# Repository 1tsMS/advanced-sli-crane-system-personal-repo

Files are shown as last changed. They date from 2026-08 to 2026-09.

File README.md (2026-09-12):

# BE Capstone Project

## Project Title

**Advanced SLI**

---

## Team Details

| Sr. No. | Name of Student | Roll No. | Branch | Email ID |
|---|---|---|---|---|
| 1 | Mohammed Salah Altaf Chogle | 41 | Automation & Robotics | 2023.mohammed.chogle@ves.ac.in |
| 2 | Ali Kalsekar | 53 | Automation & Robotics | d2024.ali.kalsekar@ves.ac.in |
| 3 | Aayush Kadam | 51 | Automation & Robotics | 2023.aayush.kadam@ves.ac.in |
| 4 |  |  |  |  |

---

## Guide Details

**Project Guide:** Gopalkrishnan Narayanan 
**Department:** Automation and Robotics  
**Institute:** VESIT, Mumbai  

---

## Problem Statement

> The aim of this project is to design and develop an affordable, retrofittable Safe Load Indicator (SLI) system for low-capacity truck-mounted pick-and-carry mobile cranes by using multi-sensor feedback (load, angle, extension, inertial data) and embedded control technology, addressing the lack of accurate, low-cost load-monitoring and safety systems available for this crane category.

---

## Abstract

Low-capacity truck-mounted pick-and-carry hydraulic cranes, commonly used at local worksites, largely lack accurate and affordable Safe Load Indicator (SLI) systems, unlike larger construction-grade cranes which have factory-fitted rated capacity indicators. Operators of these smaller cranes often rely on experience alone, increasing the risk of overloading and tipping incidents. This project proposes the design and development of an Advanced Intelligent Safe Load Indicator (AI-SLI): a sensor-driven system that monitors boom angle, extension, hydraulic pressure (as a proxy for load), and inertial motion data to provide real-time load percentage, safety alarms, and operational analytics.

The project is being developed in two parallel tracks: a custom-built scale-model truck-mounted crane platform (with independently actuated swing, telescopic extension, boom-lift, and cable-reeling axes, each with encoder and sensor feedback) used for mechanism validation and algorithm development, and eventual sensor integration on a real crane for field validation. The scale model itself is a standalone multi-axis robotic-arm project, combining mechanical design, embedded systems, and sensor fusion.

Software development follows a phased approach: starting with basic rated-capacity load-chart safety limits, followed by PID-based anti-sway control, tipping prediction using load and outrigger data, and eventually AI-based analytics such as inertial-data-driven operator scoring. The expected outcome is a working scale-model demonstrator validating the sensing and control approach, laying the foundation for deployment on a real crane.

---

## Objectives

1. To study existing Safe Load Indicator systems and identify gaps in affordability and availability for low-capacity truck-mounted cranes.
2. To design and build a multi-axis scale-model crane (swing, telescopic extension, boom lift, cable reeling) as a development and validation platform.
3. To design a sensor and control architecture capable of measuring load, angle, extension, and inertial motion.
4. To implement basic rated-capacity load-chart safety limit functionality.
5. To progressively implement advanced features: anti-sway control (PID) and tipping prediction.
6. To validate the developed system and, in later stages, apply learnings toward real crane sensor integration.

---

## Scope of the Project

- Design and fabrication of a multi-axis scale-model truck-mounted crane (mechanical + electrical)
- Sensor integration: load cell, IMU, magnetic encoders, limit switches
- Embedded firmware for motor control and sensor data acquisition
- Desktop dashboard application for live monitoring, data logging, and analytics
- Phased safety software: load-chart limits → anti-sway control → tipping prediction
- Data collection and testing on the scale model
- Preliminary exploration of real crane sensor integration (later phase, scope to be expanded as work progresses)

---

## Existing System

Large construction-grade cranes typically come with factory-fitted Rated Capacity Indicator (RCI) / SLI systems. However, small, local, truck-mounted pick-and-carry hydraulic cranes commonly used at smaller worksites usually operate without such systems.

Limitations of the current situation:

- High cost of commercial SLI systems relative to the value of low-capacity cranes
- Lack of retrofittable options for older or lower-capacity crane models
- Operators rely on experience/judgement rather than real-time load feedback
- No predictive safety features (e.g., sway or tipping warnings) on this crane category
- Limited accessibility of safety technology for smaller crane operators

---

## Proposed System

**Main idea:** An affordable, sensor-driven Safe Load Indicator system, developed and validated on a custom-built scale-model crane before targeting real crane deployment.

**How it works:** Boom angle, extension length, and load/pressure are continuously measured and combined (via a load-chart lookup) to compute real-time load percentage and trigger safety alarms. Inertial (IMU) data is used to detect motion events, assist with anti-sway damping, and support operator analytics. Data is transmitted to a desktop dashboard for live monitoring and logging.

**Major components:** Multi-axis scale-model crane (swing, telescopic extension, boom lift, cable reeling), magnetic encoders, IMU, load cell, microcontroller-based control system, and a PyQt6 desktop dashboard.

**Expected benefits:** Real-time load awareness, improved operator safety, a low-cost architecture suited to smaller cranes, and a foundation for future predictive safety features.

**Video** https://www.youtube.com/watch?v=u0mv6QGTxTg

---

## System Architecture

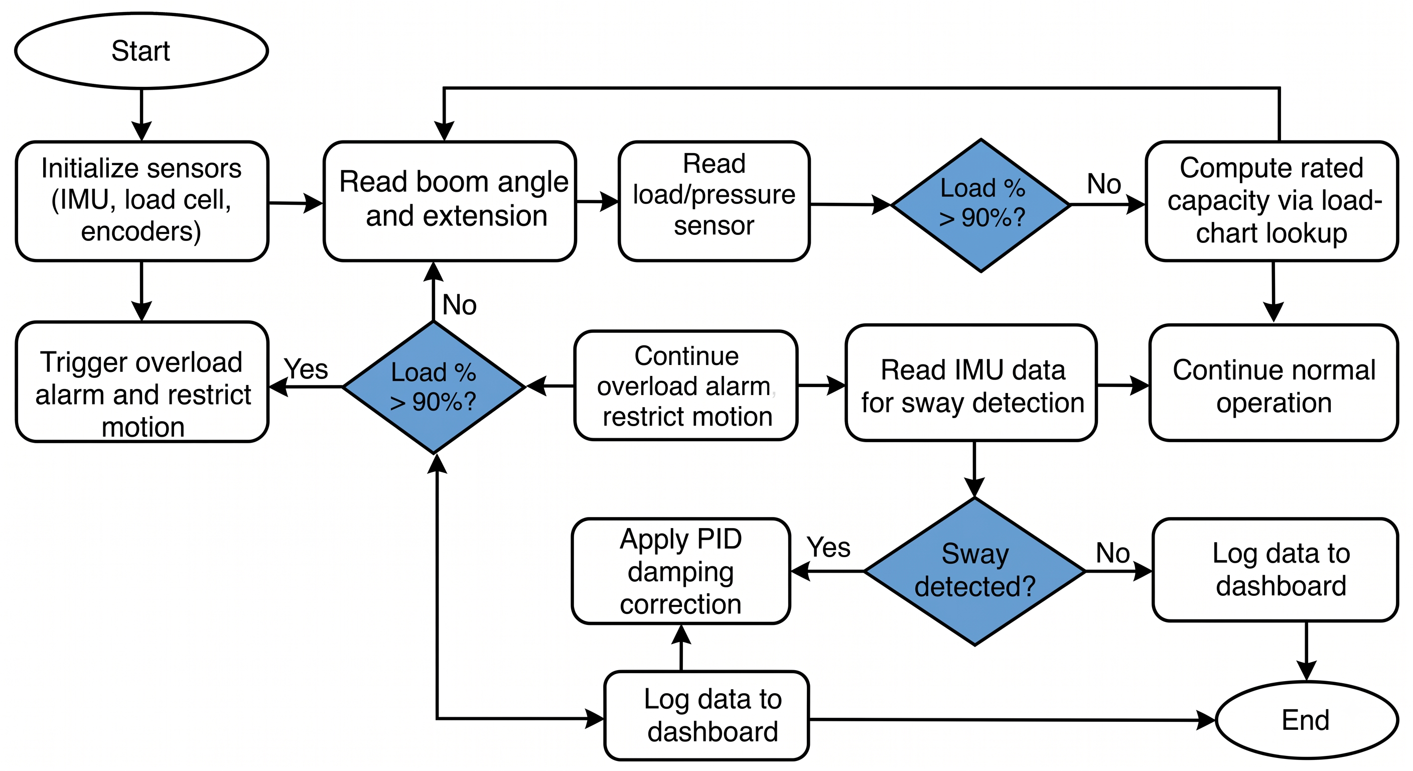
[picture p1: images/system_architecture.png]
System Architecture


---

## Hardware Requirements

| Sr. No. | Component | Specification | Quantity | Purpose |
| --- | --- | --- | --- | --- |
| 1 | NEMA17 Stepper Motor | 17HS8401 | 3 | Swing, boom lift, telescopic extension actuation |
| 2 | N20 DC Gear Motor | 150 RPM, encoder-integrated | 1 | Cable reeling / winch drive |
| 3 | Arduino Mega 2560 | — | 1 | Main controller |
| 4 | RAMPS 1.4 | — | 1 | Motor driver / sensor breakout shield |
| 5 | A4988 Stepper Driver | — | 4 | Stepper motor driving |
| 6 | AS5600 Magnetic Encoder | — | 2 | Swing and boom lift angle feedback |
| 7 | MPU6050 IMU | 6-axis | 1 | Inertial motion sensing |
| 8 | HX711 + Load Cell | 5 kg | 1 | Load sensing |
| 9 | Limit Switches | Mechanical | As required | Axis end-stop safety |
| 10 | 12V Power Supply | 12V, 10A | 1 | System power |

---

## Software Requirements

| Sr. No. | Software / Tool | Version | Purpose |
| --- | --- | --- | --- |
| 1 | Arduino IDE | — | Firmware development |
| 2 | Fusion 360 | — | Mechanical CAD design |
| 3 | Python | — | Data processing, dashboard, model training |
| 4 | PyQt6 | — | Desktop dashboard application |

---

## Technologies Used

* Embedded C++ (Arduino)
* Python (data processing, dashboard, model training)
* Arduino Mega, RAMPS 1.4, A4988 stepper drivers
* Sensor fusion (Madgwick / Kalman filtering for IMU data)
* Machine Learning (LSTM — planned for future tipping prediction phase)
* PyQt6 (desktop dashboard)
* CAD Design (Fusion 360)

---

## Methodology

Explain the step-by-step approach.

1. Literature survey
2. Problem identification
3. Requirement analysis
4. System design
5. Hardware/software development
6. Integration
7. Testing and validation
8. Documentation and publication

---

## Project Timeline

| Week / Month | Task Planned | Status |
| --- | --- | --- |
| Week 1 | Problem finalization  | Completed
| Week 2 | Literature survey | Completed |
| Week 3 | Requirement analysis  | Completed |
| Week 4 | System design | Completed |
| Week 5 | Prototype development | In Progress |
| Week 6 | Testing | Pending |
| Week 7 | Documentation | Pending |
| Week 8 | Paper writing | Pending |

---

## Weekly Progress Updates

Students must update this section every week.

| Week | Date | Work Completed | Work Planned for Next Week | Issues / Challenges | GitHub Commit Link |
| --- | ---- | --- | --- | --- | --- |
| Week 1 | Feb 2026 | Finalized problem statement | Begin literature survey	 | | |
| Week 2 | Mar 2026 | Literature survey | Incorporate review feedback, finalize scope | | |
| Week 3 | Apr 2026 | Incorporated review feedback/modifications; finalized scope for submission | Requirement analysis & component selection | | |
| Week 4 | Jul 2026 | Requirement analysis & component selection | | | |
| Week 5 | Jul 2026 | Researched mechanical systems for prototype design | | | |
| Week 6 | Jul 2026 | Mechanical design & 3D CAD modelling | | | |
| Week 7 | Aug 2026 | 3D printing of mechanical parts and assembly | | | |
| Week 8 | Aug 2026 | Prototype PCB and electronic configuration | | | |
| Week 8 | Aug 2026 | Prototype testing done | issues in model noted and updated laser cut files | | |
| Week 9 | Sep 2026 | | Sensor integration | | |
| Week 10 | Sep 2026 | | Firmware development | | |
| Week 11 | Sep 2026 | | Calibration & implement basic load-chart safety limits | | |
| Week 12 | Sep 2026 | | Build PyQt6 dashboard | | |
| Week 13 | Oct 2026 | | 	Implement PID-based anti-sway control; begin tipping-prediction groundwork | | |
| Week 14 | Oct 2026 | | 	Full system testing, bug fixes, results compilation, documentation | | |
| Week 15 | Oct 2026 | | Research paper writing | | |
---

## Design Files

Upload and link all design files here.

| File Type | File Name / Link | Description |
| --- | --- | --- |
| CAD Model | | |
| Circuit Diagram | | |
| PCB Design | | |
| Flowchart | | |
| Simulation File | | |

---

## Circuit Diagram

Add circuit diagram image here.

````markdown
![Circuit Diagram](images/circuit_diagram.png)
````

---

## Flowchart / Algorithm

Add flowchart image here.

````markdown
![Flowchart](images/flowchart.png)
````

### Algorithm

1. Start
2. Initialize the system
3. Read input from sensors/user
4. Process the data
5. Generate output/control action
6. Display/store/transmit result
7. Stop

---

## Implementation Details

Explain the actual implementation of the project.

### Hardware Implementation

Write details about connections, components, power supply, sensors, actuators, PCB, enclosure, etc.

### Software Implementation

Write details about code structure, libraries used, algorithms, communication protocols, database, app, cloud, etc.

---

## Code Structure

````text
BE-Capstone-Project/
│
├── README.md
├── docs/
│   ├── literature_survey.md
│   ├── project_report.pdf
│   └── presentation.pptx
│
├── hardware/
│   ├── circuit_diagram.png
│   ├── pcb_design/
│   └── cad_model/
│
├── software/
│   ├── src/
│   ├── include/
│   └── tests/
│
├── images/
│   ├── system_architecture.png
│   ├── prototype_photo.jpg
│   └── results.png
│
└── references/
    └── papers/
````

---

## How to Run the Project

### Step 1: Clone the Repository

````bash
git clone https://github.com/username/project-name.git
````

### Step 2: Install Dependencies

````bash
pip install -r requirements.txt
````

or mention specific software/library installation steps.

### Step 3: Upload / Run the Code

````bash
python main.py
````

or

````bash
arduino-cli upload -p COMx --fqbn board_name
````

### Step 4: Observe the Output

Mention the expected output of the project.

---

## Testing and Results

| Test No. | Test Description | Expected Result | Actual Result | Status |
| --- | --- | --- | --- | --- |
| 1 | | | | Pass / Fail |
| 2 | | | | Pass / Fail |
| 3 | | | | Pass / Fail |

---

## Result Images / Videos

Add images or videos of the working prototype.

````markdown
![Prototype](images/prototype_photo.jpg)
````

Video Link:

````markdown
[Project Demo Video](https://drive.google.com/your-video-link)
````

---

## Applications

Mention real-world applications of the project.

1.
2.
3.
4.

---

## Advantages

1.
2.
3.
4.

---

## Limitations

1.
2.
3.
4.

---

## Future Scope

Mention possible improvements.

1.
2.
3.
4.

---

## Research Paper / Publication

| Item | Details |
| --- | --- |
| Paper Title | |
| Conference / Journal Name | |
| Paper Status | Not Started / Drafting / Submitted / Accepted / Published |
| Submission Date | |
| Paper Link | |

---

## References

Add references in IEEE format.

Example:

````text
[1] Junqi Li, Qing Dong, "A Development Method for Load Adaptive Matching Digital Twin System of Bridge Cranes," Journal/Conference Name, vol. X, no. Y, pp. xx-yy, Year.
[2] Dae-Ho Jang, Gi-Tae Roh, "Simulation-Based Optimization of Crane Lifting Position and Capacity Using a Construction Digital Twin for Prefabricated Bridge Deck Assembly"
[3] Yihai Fang, Yong K. Cho, "A Framework for Real-time Pro-active Safety Assistance for Mobile Crane Lifting Operations"
[4] Datasheet / Website / Book reference.
````

---

## Repository Update Guidelines

Each student team must update the GitHub repository regularly.

Minimum expected updates:

* Update README every week.
* Push code changes regularly.
* Upload circuit diagrams, CAD files, PCB files, reports and presentations.
* Add weekly progress in the progress table.
* Maintain proper folder structure.
* Do not upload unnecessary temporary files.
* Each major update should have a meaningful commit message.

Example commit messages:

````text
Added problem statement and objectives
Updated system architecture diagram
Added sensor interfacing code
Updated weekly progress for Week 3
Added testing results and prototype images
````

---

## Declaration

We declare that this project work is carried out by our team as part of the BE Capstone Project. The work will be regularly updated on GitHub and all references used will be properly cited.

---

## License

This project is for academic use only.

Optional:

````text
MIT License / Creative Commons / Institute Use Only
````

````
````

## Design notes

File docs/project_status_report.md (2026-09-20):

# Advanced SLI — Project Status Report
**Date:** September 2026 | **Ref:** [software_design_plan.md](./software_design_plan.md)

---

## Build Phase Status

| Phase | Description | Status |
|---|---|---|
| **Phase 1** | It Talks — end-to-end data pipeline | ✅ Complete |
| **Phase 2** | It Looks Good — full UI + controls | ✅ Complete |
| **Phase 3** | It's Smart — load calculation & safety | 🔴 Pending |
| **Phase 4** | It Prevents Disaster — PID anti-sway | 🔴 Not Started |

---

## What's Done

### Layer 1 — ESP32 Firmware (FreeRTOS)
- **3-task FreeRTOS skeleton** running: `SensorTask` (100Hz, Core 1), `TelemetryTask` (50Hz, Core 0), `CommandTask` (event-driven, Core 0)
- **`$T` telemetry packet** streaming at 50Hz over USB serial — all 16 fields present and parsed
- **Custom G-code protocol** implemented — `M1–M4`, `M0 Ax`, `T0` E-stop, `CAL0–2`, `DBG`, `LC`
- **UART2 bridge** to Arduino Mega working (`GPIO23/27`)
- **All sensor drivers written and functional:**
  - `AS5600Driver` — supports all 3 buses (Wire, Wire1, SoftI2C)
  - `MPU6050Driver` — backed by `Adafruit_MPU6050`, complementary filter for roll/pitch
  - `HX711Driver` — load cell with tare and calibration factor
  - `FSRReader` — 4-channel ADC for outrigger sensors
  - `N20Encoder` — quadrature interrupt-based encoder + DRV8833 motor control
- **NVS Flash persistence** — telescope scale (`tele_scale`) and invert (`tele_inv`) survive power cycles via `Preferences`
- **Calibration commands extended** — `CAL2 S<scale> I<invert>` to tune telescope parameters at runtime without reflashing

### Layer 2 — Python Backend
- **FastAPI + pyserial** running at `localhost:8000`
- **WebSocket** telemetry broadcast at 50Hz to frontend
- **All REST endpoints** live: `/api/connect`, `/api/command`, `/api/status`, `/api/calibrate/tare|imu|tele`, `/api/estop`, `/api/debug/scan`, `/api/loadchart/*`
- **CSV session logger** — auto-logs each session with timestamp
- **Command router** with regex validation — rejects invalid commands before they hit serial
- **`TeleCalibrateRequest` model** — `CAL2 S... I...` built and sent from `/api/calibrate/tele`

### Layer 3 — Frontend Dashboard
- **Dark industrial UI** — Inter + JetBrains Mono, electric cyan accents (`#00D4FF`)
- **Sidebar navigation** — Dashboard, Debug & Calibrate, Settings, Data Logger, Load Chart (placeholder)
- **Dashboard tab** — Live telemetry panels, 3× circular arc gauges (Load%, Boom Angle, Tilt), 2D crane visualizer, outrigger FSR corner view
- **Motor Controls** — Hold-to-move buttons for all 4 axes (M1–M4), global speed slider (250–2500 steps/s, center=1000), E-stop header button
- **Xbox Gamepad API** — full axis mapping (Left Stick=Swing/Boom, Right Stick=Extend, Triggers=Winch)
- **Debug & Calibrate tab:**
  - Hardware status (I2C scan)
  - Load cell tare, IMU zero with axis mapping UI
  - **Telescope calibration panel** — live encoder readout, M3 motor jog (press-and-hold), ruler auto-calibration tool (computes scale from measured travel), manual scale/invert inputs, Save to Flash button
- **Settings tab** — COM port selection, baud, connect/disconnect
- **2D Crane Visualizer** — base boom (225mm constant) + telescoping extension stage with graduation marks + `+XX mm` badge

### Arduino Mega Executor
- Motor commands received on `Serial1` from ESP32
- 3 axes on RAMPS 1.4: **Swing → X**, **Boom Lift → Z**, **Telescope Extend → Y**
- Default speed: 1000 steps/s, range 250–2500 steps/s
- E-stop (`T0`) disables all drivers

---

## Libraries: Custom vs Standard

### Why Custom Drivers

| Component | Why not standard |
|---|---|
| `AS5600Driver` | No library supports 3 AS5600s (all fixed at `0x36`) on 3 separate buses. Custom driver takes `Wire`, `Wire1`, or `SoftI2C` as constructor arg. Essential for multi-encoder setup. |
| `SoftI2C` | ESP32 has only 2 hardware I2C peripherals. 3rd bus (telescope AS5600, GPIO32/33) needs bit-bang. AVR-targeted `SoftwareWire` won't work. Custom impl mirrors `TwoWire` API, tuned at 8µs bit delay (~60kHz) for capacitive wire lengths. |
| `HX711Driver` | Standard `HX711` library uses blocking `delay()`, which starves FreeRTOS tasks. Custom driver is non-blocking — returns cached value if data not ready, keeping `SensorTask` on its 100Hz deadline. |

### Standard Libraries Used

| Library | Layer | Role |
|---|---|---|
| `Adafruit_MPU6050` + `Adafruit_Sensor` | ESP32 | IMU hardware abstraction |
| `Preferences` (ESP-IDF built-in) | ESP32 | NVS flash key-value for calibration |
| `FreeRTOS` (bundled with ESP32 Arduino) | ESP32 | Task scheduling, mutexes, queues |
| `FastAPI` + `uvicorn` | Python | ASGI REST + WebSocket server |
| `pyserial` | Python | USB serial to ESP32 |
| `React 19` + `Vite 8` | Frontend | UI framework and build tooling |
| `Lucide React` | Frontend | SVG icon library |
| `Recharts` | Frontend | Live rolling charts |
| `Gamepad API` (W3C browser API) | Frontend | Xbox controller input |

---

## Current Issues

### 🔴 Telescope Extension — Encoder Jumpiness
- AS5600 on SoftI2C (GPIO32/33) produces spike deltas at the 0°/360° wrap boundary — 30mm physical travel was reading as 110mm.
- **Software mitigations applied:** 45° glitch gatekeeper (single-frame delta > 45° discarded), shortest-path angular accumulation, switched to `REG_ANGLE` (0x0E) for AS5600 internal hardware filter, SoftI2C bit delay increased to 8µs.
- **Current state:** Improved but still jumpy under vibration. Runtime calibration (ruler tool in Debug tab) works but is sensitive to slippage.
- **Root causes:** Long SoftI2C wires (capacitance), inconsistent magnet air-gap, AS5600 has no quadrature redundancy unlike hall-effect encoders.
- **Mechanical fix needed:** Tighten motor-to-stage coupling, reduce magnet-to-IC gap, shorten SoftI2C wiring harness.

### 🔴 N20 Winch — One Direction Not Working
- Motor only runs in reverse. Forward direction (via DRV8833 AIN1/AIN2 on GPIO13/14) produces no motion.
- **Suspected cause:** DRV8833 IC fault — one H-bridge half likely dead.
- **Action:** Replace DRV8833 module. Reverify AIN1/AIN2 polarity against `n20_test` sketch after replacement.
- **Rope length measurement:** Encoder interrupt code (GPIO18/19) is written but `N20_TICKS_PER_REV=840` and `ROPE_DRUM_DIAMETER_MM=20mm` are guesses — require physical measurement post-repair.

### 🟡 Load Cell — Not Properly Calibrated
- `HX711_DEFAULT_SCALE = 122000.0` counts/kg is a rough estimate from `loadcell_approx` test.
- No 2-point calibration with known reference weights done on final mechanical setup.
- Boom-angle compensation (`W_actual = F_measured / cos(θ)`) is planned for Phase 3 — currently `actualLoadKg` = raw reading, no compensation.

### 🟡 IMU / MPU6050 — Not Calibrated on Final Hardware
- Complementary filter active, gyro zero-offset calibration function exists (`calibrateGyro()`).
- Axis mapping UI in Debug tab implemented but proper static calibration not performed on final assembled crane.

### 🟡 Hardware — Outriggers & Hook/Rope Incomplete
- Outriggers: 3D printed and assembled. FSR sensors load. Minor adjustment needed — not all 4 corners show equal distribution under a centred load.
- Hook: Not yet designed or fabricated.
- Rope: No rope/drum assembly. N20 drum diameter unverified.

---

## Remaining Work (Priority Order)

1. Replace DRV8833 → verify N20 bidirectional operation
2. Measure actual N20 encoder ticks/rev and drum diameter → update `config.h`
3. Design and fabricate hook + rope assembly, mount on boom tip + drum
4. Proper 2-point load cell calibration → update or make `HX711_DEFAULT_SCALE` runtime-tunable
5. IMU static calibration on level assembled crane → run `CAL1`
6. Mechanical telescope fix (coupling, air-gap, wiring) → re-evaluate encoder noise
7. Outrigger FSR equalisation
8. **Phase 3 firmware:** `SafetyTask`, boom-angle load compensation, load chart lookup
9. Load Chart editor tab — upload LC entries from dashboard
10. Phase 4 — PID anti-sway (lower priority)

---

## Not Started (From Plan)

- `SafetyTask` — load chart lookup, alarm escalation
- Boom-angle compensation activated (code exists, not wired in)
- Load Chart editor UI tab
- Data Logger tab (session CSV viewer + rolling chart)
- PID anti-sway task
- 3D crane visualizer (future scope)

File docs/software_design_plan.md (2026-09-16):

# Advanced SLI — Software System Design Plan (v2)

## Overview

A three-layer software system for the Advanced Safe Load Indicator. This version incorporates RTOS fundamentals, boom-angle load compensation math, updated dashboard layout, and a phased firmware plan starting with bare telemetry.

---

## Table of Contents

1. [FreeRTOS Deep-Dive](#1--freertos-deep-dive-for-esp32)
2. [System Architecture](#2--system-architecture-3-layer)
3. [ESP32 Firmware Design](#3--layer-1--esp32-firmware-freertos)
4. [Load Calculation Physics](#4--load-calculation--boom-angle-compensation)
5. [Mega Executor Firmware](#5--mega-executor-firmware)
6. [Communication Protocol](#6--communication-protocol--custom-g-code)
7. [Python Middleware](#7--layer-2--python-middleware)
8. [Frontend Dashboard](#8--layer-3--frontend-electron--react)
9. [Folder Structure](#9--folder-structure)
10. [Build Phases](#10--build-phases)
11. [Open Decisions](#11--remaining-decisions)

---

## 1 — FreeRTOS Deep-Dive for ESP32

### What is RTOS and Why Do We Need It?

On a regular Arduino (or any bare-metal loop), your code runs like this:

```
void loop() {
    readSensors();     // takes ~5ms
    runSafetyCheck();  // takes ~2ms
    sendTelemetry();   // takes ~3ms (blocked waiting for Serial buffer)
    checkCommands();   // takes ~1ms
    controlMotors();   // takes ~1ms
}
// Total: ~12ms per cycle → ~83Hz max
// BUT: if sendTelemetry() blocks for 50ms (buffer full), EVERYTHING waits
```

**The problem**: Everything runs sequentially in one big loop. If one function takes longer than expected (sensor I2C timeout, serial buffer full, etc.), *everything* else gets delayed. Your safety check doesn't run. Your motor control stutters. Bad news for a crane.

**FreeRTOS solves this** by letting you split your code into **independent tasks** that run "at the same time". The ESP32 has **two CPU cores**, and FreeRTOS can actually run two tasks *truly in parallel* + rapidly switch between others.

### Core RTOS Concepts You Need

#### 1. Tasks (like threads)

A **task** is just a function that runs in its own infinite loop, independently from everything else. Each task has:
- A **priority** (higher priority = gets CPU time first)
- A **stack size** (memory allocated for its local variables)
- A **core assignment** (ESP32 has Core 0 and Core 1)

```cpp
// This is a FreeRTOS task — it runs forever, independently
void SensorTask(void *pvParameters) {
    while (true) {
        readAllSensors();
        vTaskDelay(pdMS_TO_TICKS(10));  // Sleep 10ms → runs at ~100Hz
    }
}

// Create it in setup()
void setup() {
    xTaskCreatePinnedToCore(
        SensorTask,     // function to run
        "SensorTask",   // name (for debug)
        4096,           // stack size in bytes
        NULL,           // parameter to pass
        5,              // priority (higher = more important)
        NULL,           // task handle (for controlling it later)
        1               // core to run on (0 or 1)
    );
}
```

#### 2. `vTaskDelay()` — Cooperative Sleeping

When a task calls `vTaskDelay(pdMS_TO_TICKS(10))`, it tells FreeRTOS: *"I'm done for now, wake me up in 10ms."* During those 10ms, **other tasks get to run**. This is how multiple tasks share a single CPU core.

> [!IMPORTANT]
> **Never use `delay()` in FreeRTOS!** Arduino's `delay()` blocks the entire core and starves other tasks. Always use `vTaskDelay()`.

#### 3. `vTaskDelayUntil()` — Precise Periodic Timing

`vTaskDelay()` sleeps for X ms *after* your work finishes. If your work takes 3ms and you delay 10ms, the actual period is 13ms — it drifts.

`vTaskDelayUntil()` sleeps *until* the next absolute time. If your period is 10ms and work takes 3ms, it sleeps exactly 7ms. Rock-solid frequency.

```cpp
void TelemetryTask(void *pvParameters) {
    TickType_t lastWakeTime = xTaskGetTickCount();
    const TickType_t period = pdMS_TO_TICKS(20);  // 50Hz exactly

    while (true) {
        sendTelemetryPacket();
        vTaskDelayUntil(&lastWakeTime, period);  // Runs at exactly 50Hz
    }
}
```

#### 4. Shared Data Problem — Queues & Mutexes

If `SensorTask` writes to `boomAngle` and `TelemetryTask` reads it at the same time, you get **data corruption** (torn reads — half-updated values). Two solutions:

**Mutex (Mutual Exclusion Lock):**
```cpp
SemaphoreHandle_t dataMutex = xSemaphoreCreateMutex();

// In SensorTask:
xSemaphoreTake(dataMutex, portMAX_DELAY);  // Lock
sensorData.boomAngle = readBoomAngle();     // Write safely
xSemaphoreGive(dataMutex);                  // Unlock

// In TelemetryTask:
xSemaphoreTake(dataMutex, portMAX_DELAY);   // Lock
float angle = sensorData.boomAngle;          // Read safely
xSemaphoreGive(dataMutex);                   // Unlock
```

**Queue (Thread-Safe Pipe):**
```cpp
QueueHandle_t commandQueue = xQueueCreate(10, sizeof(Command));

// Frontend sends command → CommandTask receives it
// Producer:
Command cmd = parseGCode("M1 S200 D1");
xQueueSend(commandQueue, &cmd, 0);

// Consumer (MotorTask):
Command received;
if (xQueueReceive(commandQueue, &received, portMAX_DELAY)) {
    executeMotorCommand(received);
}
```

#### 5. ESP32 Dual-Core Strategy

The ESP32 has **two cores**. WiFi/BLE run on Core 0 by default. We split our tasks strategically:

```
┌─────────────────────────────────────────────────┐
│                   CORE 1                         │
│  (Dedicated to time-critical real-time work)     │
│                                                  │
│  SensorTask     [100Hz, Priority 5]              │
│  SafetyTask     [50Hz,  Priority 6 — HIGHEST]    │
│  PIDTask        [50Hz,  Priority 5]              │
│                                                  │
│  → These MUST run on time, no exceptions         │
├─────────────────────────────────────────────────┤
│                   CORE 0                         │
│  (Handles communication, non-critical work)      │
│                                                  │
│  TelemetryTask  [50Hz,  Priority 3]              │
│  CommandTask    [Event, Priority 4]              │
│  MegaBridgeTask [On-demand, Priority 3]          │
│                                                  │
│  → Important but can tolerate slight delays      │
└─────────────────────────────────────────────────┘
```

**Why this split?**
- If serial communication hiccups on Core 0, your sensor reading and safety checks on Core 1 **keep running perfectly** — they're on a completely separate CPU.
- `SafetyTask` has the highest priority on Core 1, so even if `SensorTask` is mid-read, a safety alarm will preempt it immediately.

#### 6. Task Communication Flow (Our System)

```
                        ┌──────────────┐
                        │  SensorTask  │ ← reads all hardware
                        │   (Core 1)   │
                        └──────┬───────┘
                               │ writes to shared struct (mutex-protected)
                               ▼
                     ┌────────────────────┐
                     │  SensorData struct │ ← single source of truth
                     │  (mutex-guarded)   │
                     └──┬──────┬─────┬───┘
                        │      │     │
              ┌─────────▼──┐   │   ┌─▼────────────┐
              │ SafetyTask │   │   │  PIDTask      │
              │  (Core 1)  │   │   │  (Core 1)     │
              │ checks     │   │   │ anti-sway     │
              │ load limits│   │   │ compensation  │
              └─────────┬──┘   │   └──┬────────────┘
                        │      │      │
                        ▼      ▼      ▼
              ┌─────────────────────────────┐
              │     TelemetryTask (Core 0)  │
              │  reads struct → formats $T  │
              │  → Serial.println()         │
              └─────────────────────────────┘

  PC Command ──→ Serial RX ──→ CommandTask (Core 0)
                                    │
                                    ▼ (via Queue)
                              MegaBridgeTask (Core 0)
                                    │
                                    ▼ UART2
                              Arduino Mega (stepper motors)
```

#### Summary: What You Get From RTOS

| Without RTOS (bare loop) | With FreeRTOS |
|---|---|
| One thing at a time, sequentially | Multiple things truly in parallel |
| One slow function delays everything | Tasks are independent, can't block each other |
| No priority — safety check waits for serial | Safety has highest priority, always runs first |
| Timing drifts as code grows | `vTaskDelayUntil` = rock-solid frequencies |
| Hard to add features without breaking timing | Add a new task = zero impact on existing ones |

---

## 2 — System Architecture (3-Layer)

```
┌────────────────────────────────────────────────────────────────────────┐
│                     LAYER 3 — FRONTEND (Desktop App)                   │
│               Electron + React + TypeScript + Vite                      │
│  Dark Glassmorphism Industrial UI │ WebSocket Client │ Xbox Gamepad     │
└────────────────────────────────┬───────────────────────────────────────┘
                                 │ WebSocket (ws://localhost:8765)
                                 │ REST API  (http://localhost:8000)
┌────────────────────────────────▼───────────────────────────────────────┐
│                    LAYER 2 — MIDDLEWARE (Python)                        │
│                  FastAPI + WebSocket + pyserial                         │
│     Serial Reader │ Packet Parser │ Command Router │ CSV Logger         │
└────────────────────────────────┬───────────────────────────────────────┘
                                 │ USB Serial (115200 baud)
┌────────────────────────────────▼───────────────────────────────────────┐
│                    LAYER 1 — FIRMWARE (ESP32)                           │
│                    Arduino + FreeRTOS                                   │
│  SensorTask │ SafetyTask │ PID │ TelemetryTask │ CommandTask │ Mega TX  │
│                                                                        │
│        UART2 ──→ Arduino Mega + RAMPS 1.4 (Motor Executor)             │
└────────────────────────────────────────────────────────────────────────┘
```

---

## 3 — Layer 1 — ESP32 Firmware (FreeRTOS)

### Shared Data Struct

```cpp
struct SensorData {
    // Raw sensor values
    float boomAngleRaw;     // degrees from AS5600
    float extensionMM;      // mm from AS5600 rotation → linear conversion
    float swingAngleDeg;    // degrees from AS5600
    float loadCellRaw;      // kg from HX711 (raw, uncorrected)
    float ropeLengthMM;     // mm from N20 encoder ticks
    float imuRoll;          // degrees from MPU6050 (Madgwick-filtered)
    float imuPitch;         // degrees
    float swayAccelX;       // m/s² lateral sway
    uint16_t fsr[4];        // ADC values (0–4095) for outrigger sensors

    // Computed values
    float actualLoadKg;     // boom-angle-compensated true load
    float safeLoadLimitKg;  // from load chart at current angle + extension
    float loadPercent;      // (actualLoadKg / safeLoadLimitKg) * 100

    // Status
    uint8_t alarmLevel;     // 0=OK, 1=WARN (80%), 2=CRITICAL (100%), 3=E-STOP
    bool sensorsOK;         // all I2C devices responding
};
```

### FreeRTOS Tasks — Phased Implementation

#### Phase 1 (Week 9): Bare Bones — Just Read + Send

Only 3 tasks, no safety logic, just get data flowing end-to-end:

| Task | Core | Priority | Rate | What it does |
|---|---|---|---|---|
| `SensorTask` | Core 1 | 5 | 100Hz | Read all sensors, write to `SensorData` (mutex) |
| `TelemetryTask` | Core 0 | 3 | 50Hz | Read `SensorData` → format `$T` → Serial USB |
| `CommandTask` | Core 0 | 4 | Event | Parse incoming G-code → forward to Mega via UART2 |

#### Phase 2 (Week 11): Add Safety

| Task | Core | Priority | Rate | What it does |
|---|---|---|---|---|
| `SafetyTask` | Core 1 | **6** | 50Hz | Load chart lookup, alarm level, load% calculation |

#### Phase 3 (Week 13): Add PID Anti-Sway

| Task | Core | Priority | Rate | What it does |
|---|---|---|---|---|
| `PIDTask` | Core 1 | 5 | 50Hz | IMU sway → PID → swing motor correction |

This way we **validate the whole pipeline first** before adding complexity.

---

## 4 — Load Calculation — Boom Angle Compensation

### The Problem

The load cell is mounted at the boom tip (or on the cable/hook). As the boom tilts, the **gravitational component** acting along the load cell's axis changes.

Imagine holding a weight on a stick:
- Stick horizontal (0°) → the load cell sees maximum force (full weight hangs straight down)
- Stick at 45° → the load cell sees less, because some force is along the boom's axis (compression, not tension on the cell)
- Stick vertical (90°) → load cell sees near-zero (all force is boom compression)

### The Math

```
                         ╱ Boom (at angle θ from horizontal)
                        ╱
                       ╱  ← Load cell reads this component
                      ╱
           ┌─────────╱──────── Pivot
           │        θ
           │
           │  W (actual weight, straight down)
```

If the load cell measures force **perpendicular to the boom** (tension on cable hanging from tip):

```
F_measured = W × cos(θ)
```

Therefore the **actual load** (compensated) is:

```
W_actual = F_measured / cos(θ)
```

Where `θ` = boom angle from horizontal (from AS5600).

> [!WARNING]
> At very steep angles (θ → 90°), `cos(θ) → 0` and the division blows up. We clamp `θ` to max ~80° and flag unreliable readings above that.

### Implementation on ESP32

```cpp
// In SafetyTask (or SensorTask Phase 2):
float theta_rad = sensorData.boomAngleRaw * DEG_TO_RAD;
float cosTheta = cos(theta_rad);

if (cosTheta < 0.17) {  // ~80° — unreliable zone
    sensorData.actualLoadKg = -1;  // flag as unreliable
} else {
    sensorData.actualLoadKg = sensorData.loadCellRaw / cosTheta;
}
```

### What the Dashboard Shows

| Value | Label | Meaning |
|---|---|---|
| `loadCellRaw` | **Measured Load** | What the cell physically reads (varies with angle) |
| `actualLoadKg` | **True Load** | Angle-compensated actual weight hanging from hook |
| `safeLoadLimitKg` | **Safe Limit** | Max allowed load at current angle + extension |
| `loadPercent` | **Load %** | `(actualLoadKg / safeLoadLimitKg) * 100` |

---

## 5 — Mega Executor Firmware

Super simple — the Mega is a **dumb motor driver** that receives G-code on `Serial1` and controls steppers:

```cpp
// Mega receives via Serial1 (connected to ESP32 UART2)
// Same G-code format: M1 S200 D1, M2 S150 D0, T0, etc.
// Translates to RAMPS pin writes (step/dir/enable)
```

No RTOS needed on Mega. A simple `loop()` that:
1. Reads `Serial1` for incoming commands
2. Parses G-code
3. Sets stepper direction + step rate (timer-interrupt-based for smooth motion)
4. `T0` = immediate all-stop (disable all drivers)

---

## 6 — Communication Protocol — Custom G-code

### Telemetry: ESP32 → PC (50Hz push)

```
$T,<boomAngle>,<extensionMM>,<measuredLoad>,<actualLoad>,<swingAngle>,<ropeLenMM>,<fsr1>,<fsr2>,<fsr3>,<fsr4>,<imuRoll>,<imuPitch>,<safeLimit>,<loadPct>,<alarmLvl>\n
```

Example:
```
$T,45.20,340.0,2.45,3.21,12.5,550.0,120,115,130,118,1.2,0.4,5.0,64.2,1\n
```

- `alarmLvl`: 0=OK, 1=WARN, 2=CRITICAL, 3=ESTOP

### Commands: PC → ESP32

| Code | Parameters | Action |
|---|---|---|
| `T0` | — | **Emergency Stop** — all motors halt, alarm state |
| `M1` | `S<speed> D<dir>` | Swing (D0=CW, D1=CCW) |
| `M2` | `S<speed> D<dir>` | Boom Lift (D0=Up, D1=Down) |
| `M3` | `S<speed> D<dir>` | Telescope (D0=Extend, D1=Retract) |
| `M4` | `S<speed> D<dir>` | Winch (D0=Up, D1=Down) |
| `M0` | `A<axis>` | Stop specific axis (A1=swing, A2=lift, etc.) |
| `CAL0` | — | Tare load cell |
| `CAL1` | — | Zero IMU |
| `CAL2` | — | Reset extension encoder |
| `DBG` | — | Request I2C scan + sensor status report |
| `CFG` | `RATE <hz>` | Set telemetry rate |
| `LC` | `UPLOAD <n>` | Begin load chart upload (n = number of entries) |
| `LC` | `<angle>,<ext>,<limit>` | Single load chart entry (sent n times after UPLOAD) |
| `LC` | `SAVE` | Confirm & save load chart to ESP32 NVS flash |

### Debug Response: ESP32 → PC

When `DBG` is received, ESP responds with:
```
$D,I2C0,0x36,OK
$D,I2C1,0x36,OK
$D,I2C2,0x36,OK
$D,I2C2,0x68,OK
$D,HX711,OK
$D,FSR1,3412
$D,FSR2,3380
$D,FSR3,3401
$D,FSR4,3395
$D,END
```

### Load Chart Upload Flow

```
PC → ESP:   LC UPLOAD 5          (5 entries incoming)
PC → ESP:   LC 0,0,5.0           (angle=0°, ext=0mm, limit=5.0kg)
PC → ESP:   LC 15,0,4.5
PC → ESP:   LC 30,0,3.8
PC → ESP:   LC 45,0,2.5
PC → ESP:   LC 60,0,1.2
PC → ESP:   LC SAVE
ESP → PC:   $LC,OK,5             (saved 5 entries to NVS)
```

ESP stores the chart in NVS (Non-Volatile Storage) flash — persists across reboots. The dashboard editor just provides a nice UI to edit and push it.

---

## 7 — Layer 2 — Python Middleware

### Tech Stack
- **FastAPI** — REST + WebSocket server
- **pyserial-asyncio** — Non-blocking serial I/O
- **asyncio** — Async event loop
- **uvicorn** — ASGI server

### Module Structure (OOP)

```
sli_backend/
├── main.py                  # FastAPI app + startup
├── core/
│   ├── __init__.py
│   ├── serial_manager.py    # SerialManager: async open/close/read/write
│   ├── packet_parser.py     # PacketParser: $T CSV → TelemetryFrame dict
│   ├── command_router.py    # CommandRouter: validate + send G-code
│   ├── session_logger.py    # SessionLogger: CSV file per session
│   └── load_chart.py        # LoadChartManager: edit + upload LC commands
├── api/
│   ├── __init__.py
│   ├── ws_endpoint.py       # WebSocket /ws/telemetry broadcast
│   ├── rest_endpoints.py    # REST routes
│   └── models.py            # Pydantic models
└── config/
    ├── __init__.py
    └── settings.py          # Baud, port, log dir, telemetry rate
```

### Key REST Endpoints

| Method | Path | Purpose |
|---|---|---|
| GET | `/api/status` | Backend health + serial connection state |
| GET | `/api/ports` | List available COM ports |
| POST | `/api/connect` | Connect to a serial port |
| POST | `/api/disconnect` | Disconnect |
| POST | `/api/command` | Send raw G-code string |
| POST | `/api/calibrate/{type}` | Tare / IMU zero / encoder reset |
| POST | `/api/loadchart/upload` | Push load chart entries to ESP |
| GET | `/api/logs` | List session CSVs |

### WebSocket `/ws/telemetry`

Broadcasts parsed JSON at ~50Hz:
```json
{
  "boomAngle": 45.2,
  "extensionMM": 340.0,
  "measuredLoad": 2.45,
  "actualLoad": 3.21,
  "swingAngle": 12.5,
  "ropeLength": 550.0,
  "fsr": [120, 115, 130, 118],
  "imuRoll": 1.2,
  "imuPitch": 0.4,
  "safeLoadLimit": 5.0,
  "loadPercent": 64.2,
  "alarmLevel": 1,
  "timestamp": 1726474200.123
}
```

---

## 8 — Layer 3 — Frontend (Electron + React)

### Tech Stack
- **Electron** — Native desktop shell
- **React + TypeScript + Vite** — UI framework
- **Framer Motion** — Animations
- **Recharts** — Live line charts (30s rolling graph)
- **Canvas API** — 2D crane silhouette + gauges
- **Gamepad API** — Xbox controller (W3C standard)
- **Lucide React** — Icon library (clean, professional SVG icons)
- **WebSocket client** — Connects to Python backend

### Icon Library: Lucide React

Professional, consistent, MIT-licensed SVG icons. No emojis anywhere.

| Tab | Lucide Icon | Name |
|---|---|---|
| Dashboard | `LayoutDashboard` | Main operational view |
| Debug | `Bug` | I2C scan, raw values |
| Calibration | `SlidersHorizontal` | Tare, zero, reset |
| Data Logger | `Activity` | Session logs + live graph |
| Controller | `Gamepad2` | Xbox mapping |
| Settings | `Settings` | Port, baud, config |
| Load Chart | `Table2` | Chart editor + upload |

Other icons: `AlertTriangle` (warnings), `ShieldAlert` (critical), `ShieldCheck` (safe), `Power` (E-stop), `Plug` (connection), `Gauge` (gauges).

### Visual Design — Dark Glassmorphism + Industrial

| Element | Value |
|---|---|
| Background | `#0C0E13` with subtle dot grid pattern |
| Glass Cards | `rgba(255,255,255,0.04)`, `backdrop-filter: blur(16px)`, `border: 1px solid rgba(255,255,255,0.08)` |
| Primary Accent | Electric Cyan `#00D4FF` |
| Warning | Amber `#FFB347` |
| Danger/Alert | Crimson `#FF3B3B` |
| Safe/OK | Emerald `#00E676` |
| Typography | `Inter` (Google Fonts), `JetBrains Mono` for telemetry values |
| Sidebar | `#10131A`, active tab = left cyan border accent, icon + label |
| Gauges | Circular arc gauges with glow effect on needle |

### Dashboard Tab — Updated Layout

```
┌──────────────────────────────────────────────────────────────────────────────────┐
│  ⬛ E-STOP   🟢 COM4 Connected   115200 baud           ⚠ LOAD: 64%  WARNING    │
├──────────────┬────────────────────────────┬──────────────────────────────────────┤
│              │                            │                                      │
│  TELEMETRY   │     MOTOR CONTROLS         │   2D CRANE VISUALISATION             │
│  PANELS      │                            │   (Boom silhouette + angle arc)      │
│  (glass      │   ┌────┐ ┌────┐           │   (Green/Amber/Red envelope zones)   │
│   cards)     │   │ SW◄│ │ SW►│  Swing    │   (Hook animation)                   │
│              │   └────┘ └────┘           │                                      │
│  Boom Angle  │   ┌────┐ ┌────┐           │   ┌──────────┐  ┌──────────┐         │
│  Extension   │   │ LF▲│ │ LF▼│  Lift    │   │  GAUGE   │  │  GAUGE   │         │
│  Swing Angle │   └────┘ └────┘           │   │ Load %   │  │ Boom ∠   │         │
│  Measured Ld │   ┌────┐ ┌────┐           │   └──────────┘  └──────────┘         │
│  True Load   │   │ TE+│ │ TE-│  Extend  │         ┌──────────┐                  │
│  Safe Limit  │   └────┘ └────┘           │         │  GAUGE   │                  │
│  Load %      │   ┌────┐ ┌────┐           │         │ Swing ∠  │                  │
│  Rope Len    │   │ WN▲│ │ WN▼│  Winch   │         └──────────┘                  │
│  IMU Roll    │   └────┘ └────┘           ├──────────────────────────────────────┤
│  IMU Pitch   │                            │   OUTRIGGER FSR VIEW (Overhead)      │
│              │   SPEED: [====●════]       │   [FL●] ─────────── [FR●]            │
│              │                            │    |                   |             │
│              │   XBOX: 🎮 Connected       │    |     CRANE BASE   |             │
│              │   LStick: ██░░ RStick: █░░ │    |                   |             │
│              │                            │   [RL●] ─────────── [RR●]            │
└──────────────┴────────────────────────────┴──────────────────────────────────────┘
```

**Layout columns: 25% telemetry | 30% controls | 45% visualization**

### Gauges (3 circular arc gauges)

1. **Load %** — 0–120% range, color changes: green < 60%, amber 60–80%, red 80–100%, flashing red > 100%
2. **Boom Angle** — 0–90° range, shows current boom angle, cyan accent
3. **Swing Angle** — -180° to +180°, shows crane rotation

Gauge style: dark background circular arc, glowing needle, value in center with `JetBrains Mono` font.

### Hold-to-Move Buttons

```
onPointerDown → send "M1 S<speed> D0" (start moving)
  ↓ (button held)
onPointerUp   → send "M0 A1"           (stop that axis)
```

Same for keyboard (WASD + QE), and Xbox controller axes.

### Xbox Controller (Gamepad API)

Polling via `requestAnimationFrame` loop:
- **Left Stick X** → Swing (M1)
- **Left Stick Y** → Boom Lift (M2)
- **Right Stick Y** → Telescope (M3)
- **Right Trigger** → Winch Down (M4 D1)
- **Left Trigger** → Winch Up (M4 D0)
- **B Button** → Emergency Stop (T0)

Deadzone: 0.15 (configurable in Controller tab). Raw axis value (0.0–1.0) → mapped to speed (0–255) → sent as G-code to Python → Serial → ESP.

**No filtering, no safety logic in frontend.** ESP is the brain.

### Left Sidebar Tabs

```
┌──────────────────┐
│ ◻ SLI Dashboard  │  ← App title / logo
├──────────────────┤
│ ▦  Dashboard     │  ← Main view (default)
│ 🪲 Debug         │
│ ⊞  Calibration   │
│ 📊 Data Logger   │
│ 🎮 Controller    │
│ ⊞  Load Chart    │
│ ⚙  Settings      │
├──────────────────┤
│ COM4 ● Connected │  ← Status footer
└──────────────────┘

(Icons shown as emoji for readability — actual implementation uses Lucide SVG icons)
```

### Debug Tab

```
┌──────────────────────────────────────────────────────────────────┐
│  I2C BUS SCAN                          RAW SENSOR VALUES         │
│  ┌────────────────────────────────┐    ┌────────────────────────┐│
│  │ Bus 0 (GPIO21/22)             │    │ AS5600 Swing: 2341     ││
│  │   0x36 AS5600 Swing    ● OK   │    │ AS5600 Boom:  1023     ││
│  │                               │    │ AS5600 Tele:  3891     ││
│  │ Bus 1 (GPIO25/26)             │    │ MPU6050 AccX: -0.032   ││
│  │   0x36 AS5600 Boom     ● OK   │    │ MPU6050 AccY:  0.981   ││
│  │                               │    │ HX711 Raw:    -234521  ││
│  │ Bus 2 (GPIO32/33)             │    │ FSR1 ADC:     3412     ││
│  │   0x36 AS5600 Tele     ● OK   │    │ FSR2 ADC:     3380     ││
│  │   0x68 MPU6050         ● OK   │    │ FSR3 ADC:     3401     ││
│  │                               │    │ FSR4 ADC:     3395     ││
│  │ HX711 (GPIO4/27)       ● OK   │    │ N20 Enc Ticks: 4210   ││
│  │ FSR ADC (GPIO34-39)    ● OK   │    └────────────────────────┘│
│  └────────────────────────────────┘                              │
│  [🔄 Refresh Scan]                                               │
└──────────────────────────────────────────────────────────────────┘
```

---

## 9 — Folder Structure

```
advanced_sli_BE_Project_2026_2027/
├── software/
│   ├── test_codes/                  # ← PRESERVED — existing test sketches
│   │   ├── 3_AS5600_test/
│   │   ├── FSR_test/
│   │   ├── RAMPS_test/
│   │   ├── conn_test/
│   │   ├── esp_serial_test/
│   │   ├── hx_711_test/
│   │   ├── mega_serial_test/
│   │   ├── mpu_hx711_test/
│   │   └── n20_test/
│   │
│   ├── firmware/                    # ← NEW — embedded firmware
│   │   ├── esp32_main/              # Main ESP32 FreeRTOS firmware
│   │   │   ├── esp32_main.ino       # Setup + task creation
│   │   │   ├── tasks/
│   │   │   │   ├── sensor_task.h/.cpp
│   │   │   │   ├── telemetry_task.h/.cpp
│   │   │   │   ├── command_task.h/.cpp
│   │   │   │   ├── safety_task.h/.cpp     (Phase 3)
│   │   │   │   └── pid_task.h/.cpp        (Phase 4)
│   │   │   ├── drivers/
│   │   │   │   ├── as5600_driver.h/.cpp
│   │   │   │   ├── mpu6050_driver.h/.cpp
│   │   │   │   ├── hx711_driver.h/.cpp
│   │   │   │   ├── fsr_reader.h/.cpp
│   │   │   │   └── n20_encoder.h/.cpp
│   │   │   ├── protocol/
│   │   │   │   ├── gcode_parser.h/.cpp
│   │   │   │   ├── telemetry_formatter.h/.cpp
│   │   │   │   └── mega_bridge.h/.cpp
│   │   │   ├── safety/
│   │   │   │   ├── load_chart.h/.cpp      (Phase 3)
│   │   │   │   └── load_calculator.h/.cpp (Phase 3)
│   │   │   └── config.h                   # Pin defs, I2C addrs, rates
│   │   │
│   │   └── mega_executor/               # Arduino Mega stepper driver
│   │       ├── mega_executor.ino
│   │       ├── gcode_parser.h/.cpp
│   │       └── stepper_controller.h/.cpp
│   │
│   └── sli_desktop/                 # ← NEW — PC software (all layers)
│       ├── backend/                 # Python FastAPI middleware
│       │   ├── sli_backend/
│       │   │   ├── core/
│       │   │   ├── api/
│       │   │   └── config/
│       │   ├── main.py
│       │   └── requirements.txt
│       │
│       └── dashboard/               # Electron + React frontend
│           ├── electron/
│           ├── src/
│           │   ├── components/
│           │   │   ├── panels/      # Telemetry cards
│           │   │   ├── crane2d/     # Canvas crane renderer
│           │   │   ├── gauges/      # Circular arc gauge components
│           │   │   ├── controls/    # Motor buttons, E-stop
│           │   │   ├── outrigger/   # FSR 4-corner view
│           │   │   └── tabs/        # Tab page layouts
│           │   ├── hooks/           # useWebSocket, useGamepad, useTelemetry
│           │   ├── types/           # TypeScript interfaces
│           │   └── App.tsx
│           ├── package.json
│           └── vite.config.ts
│
├── hardware/
│   ├── cad_model/
│   └── connections.md
├── docs/
├── images/
├── reference/
└── README.md
```

> [!NOTE]
> `software/test_codes/` is **completely untouched**. All new firmware goes under `software/firmware/` and all PC software goes under `software/sli_desktop/`.

---

## 10 — Build Phases

### Phase 1 — "It Talks"

**Goal**: Raw sensor data flows from ESP32 → Python → Dashboard screen. No safety, no calculation, just prove the entire pipeline works end-to-end.

**Firmware (ESP32)**:
- [ ] FreeRTOS skeleton with `SensorTask`, `TelemetryTask`, `CommandTask`
- [ ] Basic sensor drivers (AS5600 x3, MPU6050, HX711, FSR, N20 enc)
- [ ] `$T` telemetry packet at 50Hz
- [ ] G-code command parser (M1-M4, T0, CAL0-2, DBG)
- [ ] UART2 bridge to Mega

**Firmware (Mega)**:
- [ ] G-code parser on Serial1
- [ ] Stepper control (step/dir via RAMPS pins)
- [ ] T0 emergency stop

**Python Backend**:
- [ ] Serial connection manager
- [ ] `$T` packet parser
- [ ] WebSocket broadcast
- [ ] REST endpoints (connect, disconnect, command, ports)

**Frontend**:
- [ ] Electron + React + Vite scaffold
- [ ] Sidebar navigation
- [ ] Dashboard: telemetry panels (raw number display)
- [ ] Motor control buttons (hold-to-move)
- [ ] E-stop button (always visible in header bar)
- [ ] Settings tab: COM port selection + connect/disconnect

### Phase 2 — "It Looks Good & It's Fun"

**Goal**: Full visual polish, all tabs functional, controller support, data logging — the complete operational UI.

**Dashboard Visuals**:
- [ ] 2D crane Canvas renderer (boom angle + extension + hook)
- [ ] 3 circular arc gauges (Load %, Boom Angle, Swing Angle)
- [ ] Overhead FSR outrigger view
- [ ] Full glassmorphism styling + animations
- [ ] Safety status bar in header (color-coded load %)

**Tabs & Features**:
- [ ] Debug tab (I2C scan display from `$D` packets)
- [ ] Xbox controller integration (Gamepad API)
- [ ] Controller tab (button mapping + live axis display)
- [ ] Calibration tab (tare, IMU zero, encoder reset)
- [ ] CSV session logger (Python backend)
- [ ] Data Logger tab (session file list + rolling 30s chart)

### Phase 3 — "It's Smart"

**Goal**: Load calculation, safety limits, and load chart management — the actual SLI brain.

- [ ] ESP32: Load calculation (boom angle compensation)
- [ ] ESP32: `SafetyTask` with load chart lookup
- [ ] ESP32: Alarm levels (OK → WARN → CRITICAL)
- [ ] Load chart editor tab in dashboard
- [ ] Load chart upload flow (LC commands)
- [ ] Both measured + true load displayed in dashboard

### Phase 4 — "It Prevents Disaster"

**Goal**: Active sway prevention and alarm systems.

- [ ] ESP32: PID anti-sway task (IMU feedback → swing correction)
- [ ] Sway indicator in dashboard
- [ ] Audio alarm in frontend (browser Audio API)

### Future

- 3D crane visualization (Three.js — swap Canvas renderer component)
- AI operator scoring (LSTM on logged CSV data)
- Real crane sensor integration
- WiFi telemetry option

---

## 11 — Remaining Decisions

> [!NOTE]
> **Load cell mounting**: Is the load cell measuring cable tension at the boom tip, or is it inline with the hook/cable? This affects the angle-compensation formula. `F = W × cos(θ)` assumes the cell measures perpendicular force at the tip. If it's inline with the cable, the formula changes slightly.

> [!NOTE]
> **Stepper speed control on Mega**: Using timer interrupts (AccelStepper library) vs. direct `delayMicroseconds` stepping. AccelStepper gives acceleration/deceleration profiles which would feel smoother. Worth the complexity?

> [!NOTE]
> **Telemetry start trigger**: Should the ESP32 start pushing telemetry immediately on boot, or wait until the PC sends a `CFG START` command? Auto-start is simpler but could flood an unlistening port.

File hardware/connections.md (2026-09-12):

# Advanced SLI — Protoboard Connections

## Architecture

ESP32 = sensor acquisition + safety/control brain
Mega 2560 + RAMPS 1.4 = stepper motor executor (3 axes only)
N20 winch (DRV8833) = driven directly by ESP32, not RAMPS

---

## ESP32 (30-pin) — Sensor + Control Brain

### I2C — 3 separate buses (AS5600 all share address 0x36, cannot share a bus)

| Bus | Type | SDA | SCL | Device(s) |
|---|---|---|---|---|
| I2C Bus 0 | Hardware (`Wire`) | GPIO21 | GPIO22 | AS5600 — Swing |
| I2C Bus 1 | Hardware (`Wire1`) | GPIO25 | GPIO26 | AS5600 — Boom Lift |
| I2C Bus 2 | Software/bit-banged | GPIO32 | GPIO33 | AS5600 — Telescope + MPU6050 (top of boom, shares bus — different address 0x68, no conflict) |

### Analog — Outrigger Force Sensors (FSR RP-C18.3-ST)

| Signal | GPIO | Notes |
|---|---|---|
| FSR 1 | GPIO34 | ADC1, input-only pin |
| FSR 2 | GPIO35 | ADC1, input-only pin |
| FSR 3 | GPIO36 | ADC1, input-only pin |
| FSR 4 | GPIO39 | ADC1, input-only pin |

### Load Cell (Top/Hook) — HX711

| Signal | GPIO |
|---|---|
| DT | GPIO4 |
| SCK | GPIO27 |

### Winch — N20 (encoder-integrated) via DRV8833

| Signal | GPIO | Notes |
|---|---|---|
| DRV8833 AIN1 | GPIO13 | Direction/PWM |
| DRV8833 AIN2 | GPIO14 | Direction/PWM |
| DRV8833 STBY | GPIO12 (or tie to 3.3V if always-enabled) | Confirm before final wiring |
| N20 Encoder A | GPIO18 | Interrupt-capable |
| N20 Encoder B | GPIO19 | Interrupt-capable |

### Communication

| Link | ESP32 Pin | Connects To |
|---|---|---|
| UART2 TX | GPIO17 | Mega RX1 (Pin 19) |
| UART2 RX | GPIO16 | Mega TX1 (Pin 18) |
| UART0 (USB) | Built-in | PC (telemetry to PyQt dashboard) |

### Power

- 5V / 3.3V and GND common rail for all sensors (check each sensor's rated voltage individually — AS5600 and MPU6050 breakouts are typically 3.3-5V tolerant, FSR voltage divider reference should match ADC reference)

---

## Mega 2560 + RAMPS 1.4 — Motor Executor (3 stepper axes)

| Axis | RAMPS Slot | Driver | Motor |
|---|---|---|---|
| X | X | A4988 | Swing — NEMA17 |
| Y | Y | A4988 | Telescope — NEMA17 |
| Z | Z | A4988 | Boom Lift — NEMA17 |
| E0 | — | Unused | (winch moved to ESP32, not RAMPS) |

| Signal | Mega Pin | Connects To |
|---|---|---|
| Serial1 RX1 | Pin 19 | ESP32 GPIO17 (TX2) |
| Serial1 TX1 | Pin 18 | ESP32 GPIO16 (RX2) |
| Power In | RAMPS power terminal | 12V PSU |

---

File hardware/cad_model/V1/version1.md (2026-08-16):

First Prototype for the robotic arm similar to a real telescopic crane

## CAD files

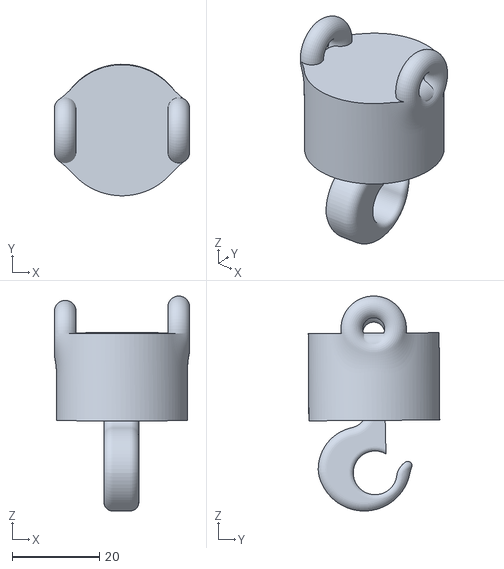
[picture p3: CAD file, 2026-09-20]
hardware/cad_model/V1/hook.stl
31.0 x 30.1 x 49.2

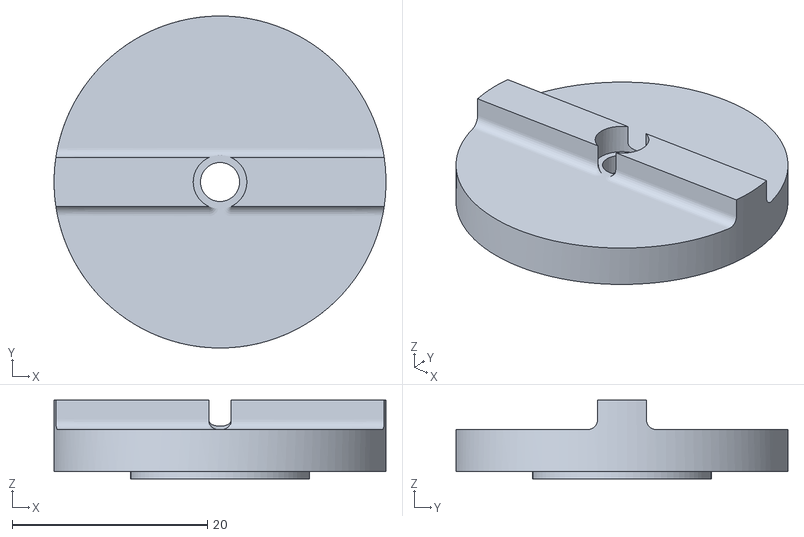
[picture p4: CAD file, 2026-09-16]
hardware/cad_model/V1/outrigger_plate.stl
34.0 x 34.0 x 8.05

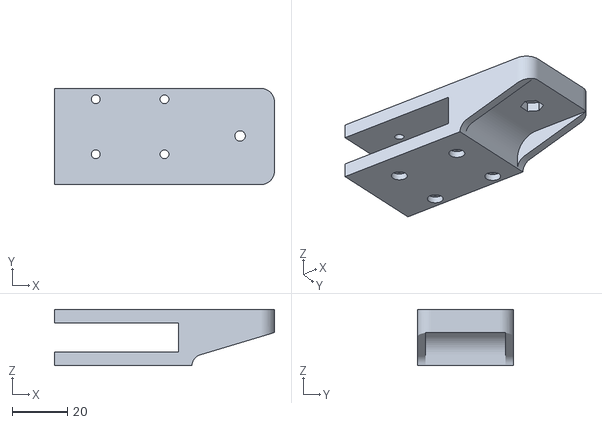
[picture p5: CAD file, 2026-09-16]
hardware/cad_model/V1/outrigger.stl
80.0 x 35.0 x 20.4

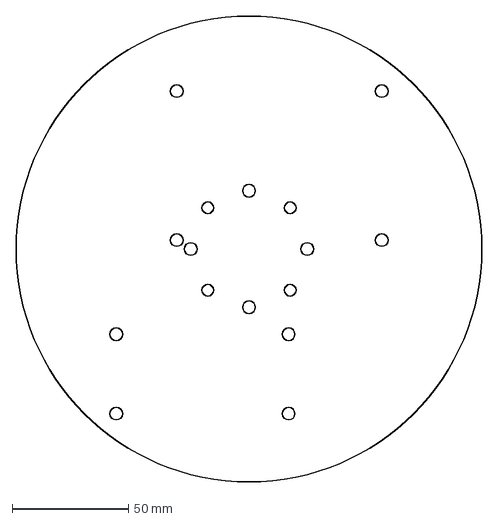
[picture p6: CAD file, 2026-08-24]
hardware/cad_model/V1/base plate2.dxf
200.0 x 200.0 mm

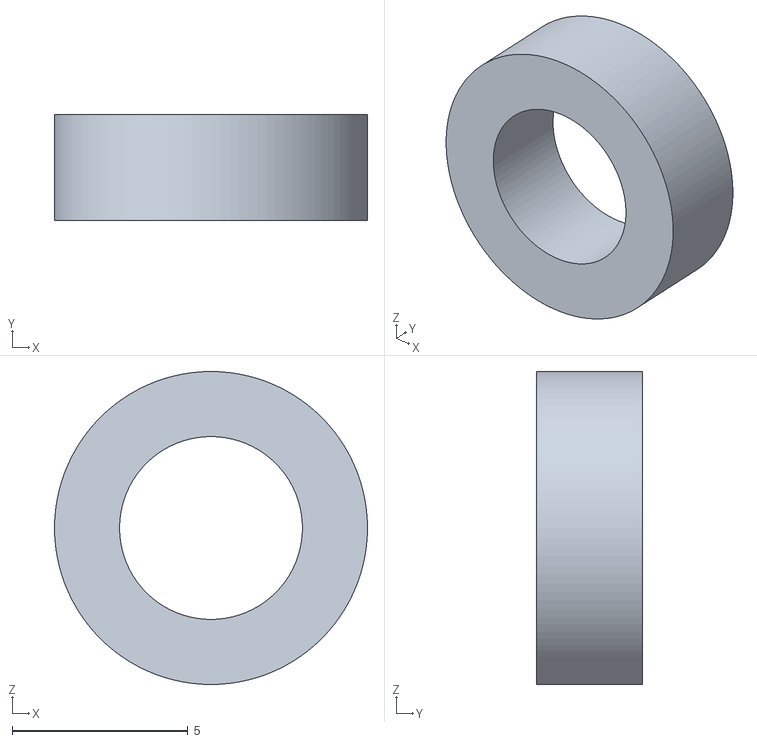
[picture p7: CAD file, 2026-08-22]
hardware/cad_model/V1/Body3.stl
8.90 x 3.00 x 8.90

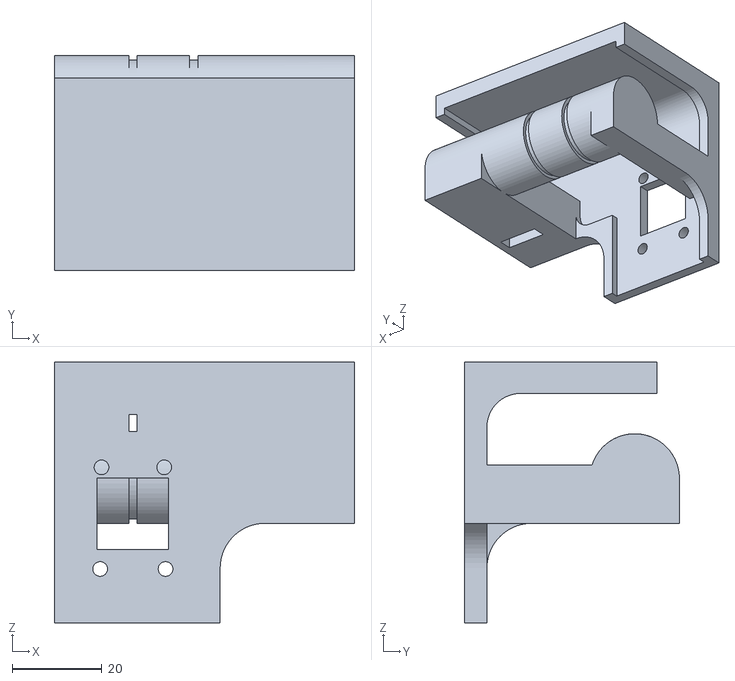
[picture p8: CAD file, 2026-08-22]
hardware/cad_model/V1/boom tip.stl
67.0 x 48.0 x 58.2

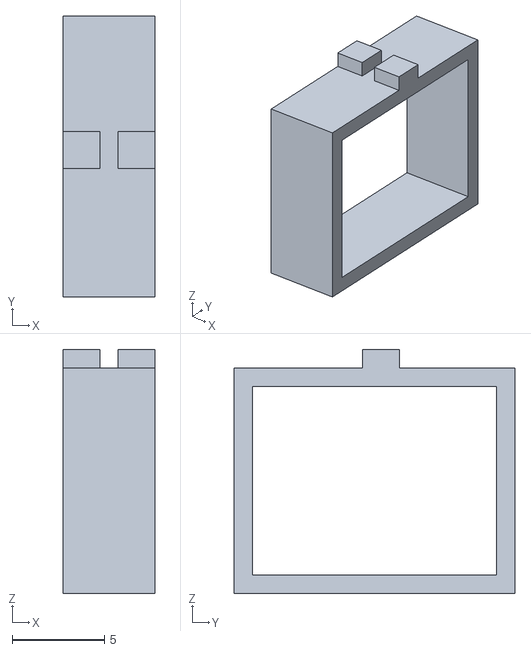
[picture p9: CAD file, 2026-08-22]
hardware/cad_model/V1/loadcell cap.stl
5.00 x 15.2 x 13.2

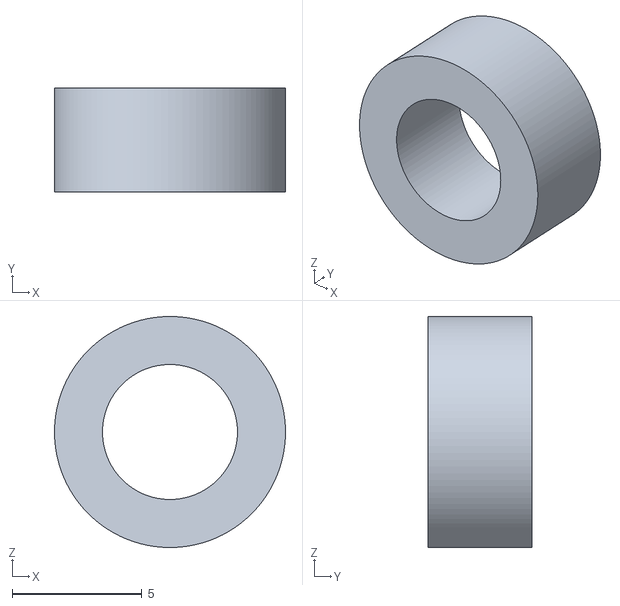
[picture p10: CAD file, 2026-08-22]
hardware/cad_model/V1/magnet mount.stl
8.90 x 4.00 x 8.90

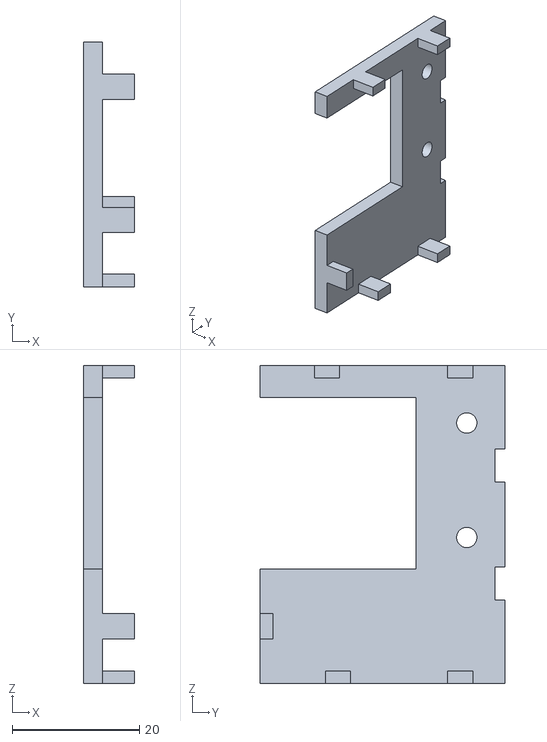
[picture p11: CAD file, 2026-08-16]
hardware/cad_model/V1/cap.stl
7.98 x 38.5 x 50.0

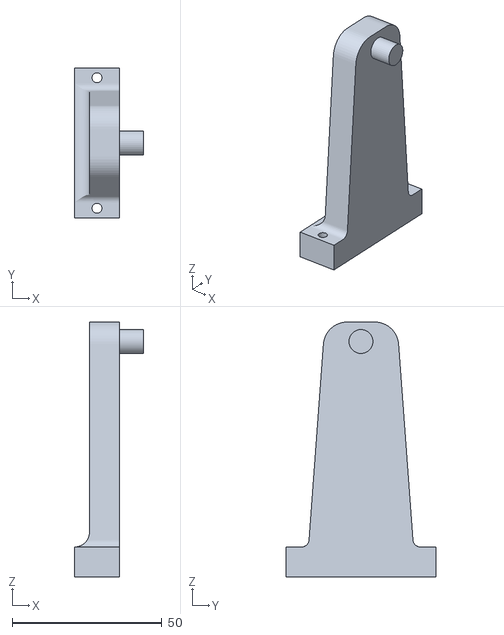
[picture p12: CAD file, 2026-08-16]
hardware/cad_model/V1/support.stl
23.0 x 50.0 x 85.0

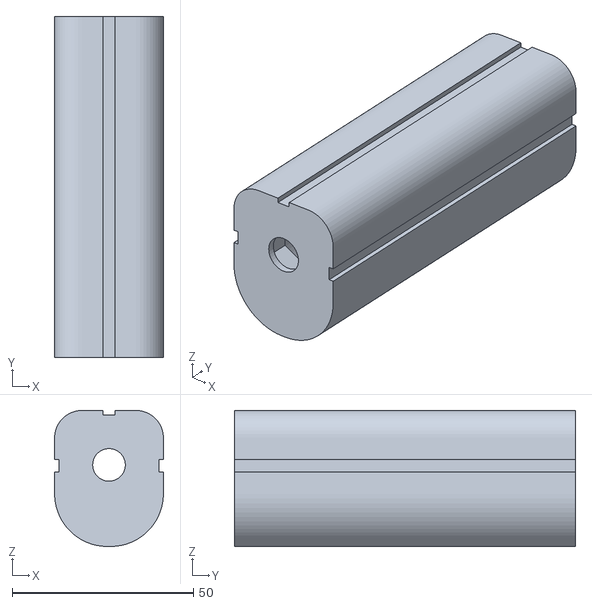
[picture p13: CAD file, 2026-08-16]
hardware/cad_model/V1/extension offset.stl
30.0 x 94.0 x 37.5

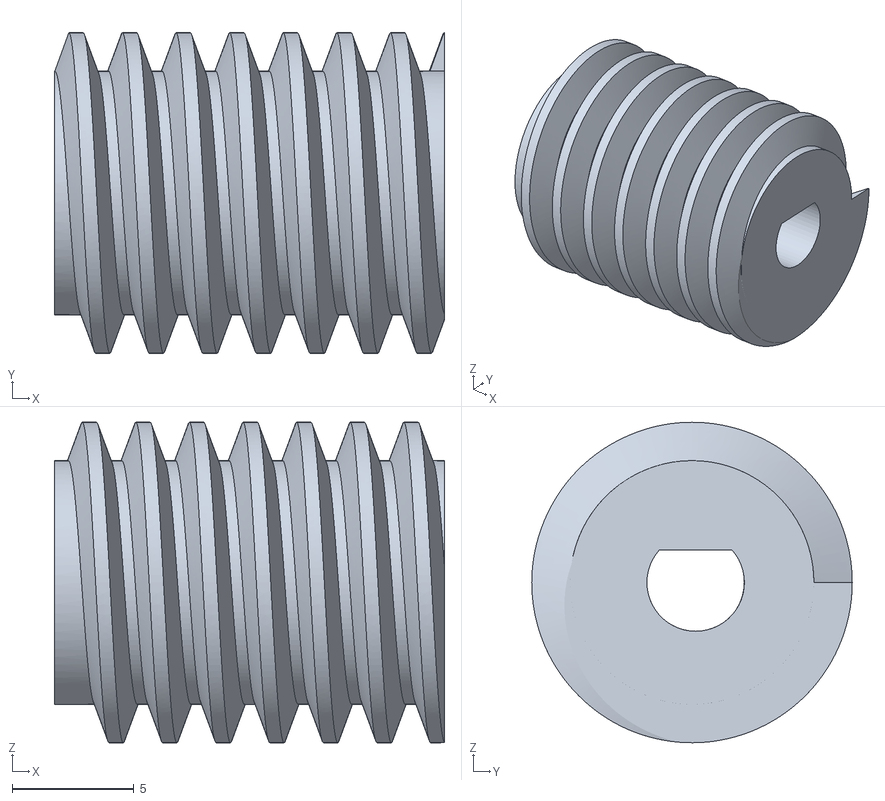
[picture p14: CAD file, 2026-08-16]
hardware/cad_model/V1/worm.stl
16.0 x 13.2 x 13.1

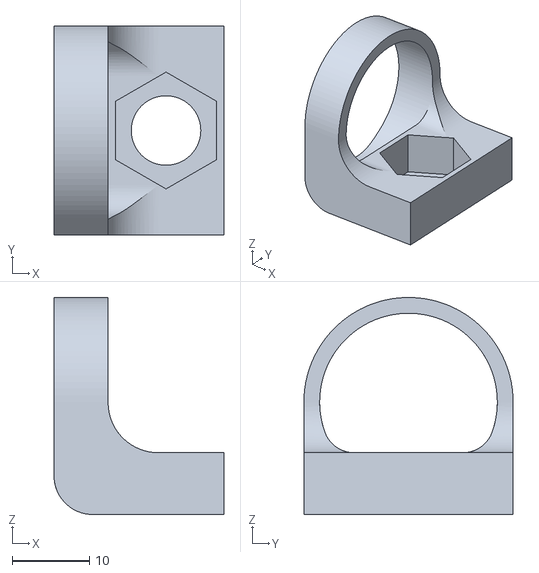
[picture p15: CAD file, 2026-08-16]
hardware/cad_model/V1/Body2.stl
22.0 x 27.1 x 28.1

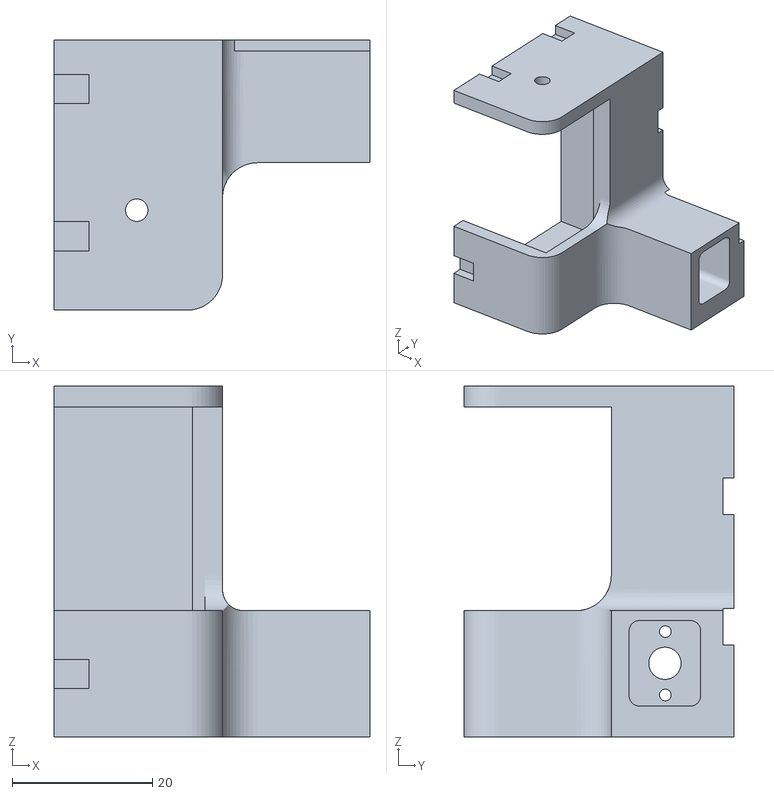
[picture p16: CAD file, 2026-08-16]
hardware/cad_model/V1/housing.stl
45.0 x 38.5 x 50.0

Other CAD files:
hardware/cad_model/V1/encoder.stl
hardware/cad_model/V1/boom.stl
hardware/cad_model/V1/mount.stl
hardware/cad_model/V1/extension.stl
hardware/cad_model/V1/Body4.stl
hardware/cad_model/V1/all.3mf
hardware/cad_model/V1/base plate.dxf
hardware/cad_model/V1/base plate.stl
hardware/cad_model/V1/coupling 2.stl
hardware/cad_model/V1/coupling.stl
hardware/cad_model/V1/drum offset.stl
hardware/cad_model/V1/drum.stl
hardware/cad_model/V1/housing offset.stl
hardware/cad_model/V1/yoke.stl

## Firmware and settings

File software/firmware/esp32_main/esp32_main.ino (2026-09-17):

// ============================================================
//  Advanced SLI — ESP32 Main Entry Point
//  FreeRTOS-based firmware for the Safe Load Indicator system.
//
//  This file:
//    1. Initializes all I2C buses and sensor drivers
//    2. Creates the shared mutex and command queue
//    3. Spawns FreeRTOS tasks pinned to specific CPU cores
//
//  Core 1 (real-time critical):
//    - SensorTask  [100Hz, Priority 5] — reads all sensors
//
//  Core 0 (communication):
//    - TelemetryTask [50Hz, Priority 3] — pushes $T packets to PC
//    - CommandTask   [event, Priority 4] — parses G-code from PC
// ============================================================
#include <Wire.h>
#include "config.h"
#include "soft_i2c.h"
#include "as5600_driver.h"
#include "mpu6050_driver.h"
#include "hx711_driver.h"
#include "fsr_reader.h"
#include "n20_encoder.h"
#include "mega_bridge.h"
#include "sensor_task.h"
#include "telemetry_task.h"
#include "command_task.h"

// ======================== GLOBAL RTOS OBJECTS ========================
SemaphoreHandle_t sensorMutex      = NULL;
QueueHandle_t     motorCommandQueue = NULL;

// ======================== SHARED SENSOR DATA ========================
SensorData sensorData;

// ======================== I2C BUSES ========================
// Bus 2: Software I2C for telescope AS5600 ONLY (MPU6050 moved to Wire/Bus0)
SoftI2C softI2C(I2C2_SDA, I2C2_SCL);

// ======================== SENSOR DRIVERS ========================
AS5600Driver swingEncoder(AS5600Driver::BUS_WIRE0);            // Bus 0 (shares with MPU)
AS5600Driver boomEncoder(AS5600Driver::BUS_WIRE1);             // Bus 1
AS5600Driver teleEncoder(AS5600Driver::BUS_SOFT, &softI2C);    // Bus 2

MPU6050Driver imu;                                             // Wire Bus 0 (GPIO 21/22)

HX711Driver loadCell(HX711_DT_PIN, HX711_SCK_PIN);
FSRReader   fsrReader;
N20Encoder  winchEncoder;

// ======================== COMMUNICATION ========================
MegaBridge megaBridge;

// ======================== SETUP ========================
void setup() {
    // --- USB Serial to PC ---
    Serial.begin(USB_BAUD);
    delay(500);
    Serial.println("\n=== Advanced SLI ESP32 Starting ===");

    // --- Initialize I2C Buses ---
    // 100kHz standard mode ensures reliable signal integrity with breadboards/crane wiring
    Serial.print("Init I2C Bus 0 (Wire 21/22)... ");
    Wire.begin(I2C0_SDA, I2C0_SCL);
    Wire.setClock(100000);
    Wire.setTimeOut(50);
    Serial.println("OK");

    Serial.print("Init I2C Bus 1 (Wire1 25/26)... ");
    Wire1.begin(I2C1_SDA, I2C1_SCL);
    Wire1.setClock(100000);
    Wire1.setTimeOut(50);
    Serial.println("OK");

    Serial.print("Init I2C Bus 2 (SoftI2C 32/33)... ");
    softI2C.begin();
    Serial.println("OK");

    // --- Initialize Sensors ---
    // Encoders initialized first to ensure clean I2C probe before high-rate IMU traffic
    Serial.print("AS5600 Swing (21/22): ");
    Serial.println(swingEncoder.begin() ? "DETECTED" : "NOT FOUND");

    Serial.print("AS5600 Boom (25/26):  ");
    Serial.println(boomEncoder.begin() ? "DETECTED" : "NOT FOUND");

    Serial.print("AS5600 Tele (32/33):  ");
    Serial.println(teleEncoder.begin() ? "DETECTED" : "NOT FOUND");

    // Initialize MPU6050 on Wire (Bus 0)
    Serial.print("MPU6050 IMU (21/22):  ");
    if (imu.begin()) {
        Wire.setClock(100000);
        Serial.println("DETECTED — Calibrating gyro (keep still)...");
        imu.calibrateGyro(200);  // Quick calibration on startup
        Wire.setClock(100000);
        Serial.println("  Gyro calibrated.");
    } else {
        Serial.println("NOT FOUND");
    }

    Serial.print("HX711 Load Cell: ");
    loadCell.begin();
    Serial.println(loadCell.isConnected() ? "DETECTED" : "NOT FOUND");

    Serial.print("FSR Readers:   ");
    fsrReader.begin();
    Serial.println("CONFIGURED (ADC1)");

    Serial.print("N20 Encoder:   ");
    winchEncoder.begin();
    Serial.println("CONFIGURED (Interrupts attached)");

    // --- Initialize Mega Bridge (UART2) ---
    Serial.print("Mega UART2:    ");
    megaBridge.begin(&Serial2);
    Serial.println("CONFIGURED");

    // --- Initialize shared sensor data to safe defaults ---
    memset(&sensorData, 0, sizeof(SensorData));
    sensorData.safeLoadLimit = 5.0f;  // Default 5kg limit
    sensorData.sensorsOK = true;

    // --- Create RTOS synchronization primitives ---
    sensorMutex = xSemaphoreCreateMutex();
    motorCommandQueue = xQueueCreate(10, sizeof(MotorCommand));

    if (!sensorMutex || !motorCommandQueue) {
        Serial.println("FATAL: Failed to create RTOS primitives!");
        while (1) delay(1000);  // Halt
    }

    // --- Initialize task subsystems ---
    sensorTask_init(
        &swingEncoder, &boomEncoder, &teleEncoder,
        &imu, &loadCell, &fsrReader, &winchEncoder
    );
    sensorTask_loadCalibration();  // Restore zero offsets and axis config from flash

    commandTask_init(
        &megaBridge, &winchEncoder, &loadCell,
        &imu, &teleEncoder, &swingEncoder, &boomEncoder
    );

    // --- Create FreeRTOS Tasks ---
    // Core 1: Time-critical sensor acquisition
    xTaskCreatePinnedToCore(
        sensorTask,              // Task function
        "SensorTask",            // Name (for debug)
        SENSOR_TASK_STACK,       // Stack size (bytes)
        NULL,                    // Parameter
        SENSOR_TASK_PRIORITY,    // Priority (5 = high)
        NULL,                    // Task handle
        1                        // Pin to Core 1
    );

    // Core 0: Telemetry push to PC
    xTaskCreatePinnedToCore(
        telemetryTask,
        "TelemetryTask",
        TELEMETRY_TASK_STACK,
        NULL,
        TELEMETRY_TASK_PRIORITY,  // Priority 3
        NULL,
        0                         // Pin to Core 0
    );

    // Core 0: Command parser (PC → ESP32)
    xTaskCreatePinnedToCore(
        commandTask,
        "CommandTask",
        COMMAND_TASK_STACK,
        NULL,
        COMMAND_TASK_PRIORITY,    // Priority 4
        NULL,
        0                         // Pin to Core 0
    );

    Serial.println("=== All tasks started. System ready. ===\n");
}

// ======================== LOOP ========================
// With FreeRTOS, loop() is effectively idle.
// We keep it empty — all work is done in tasks.
void loop() {
    vTaskDelay(pdMS_TO_TICKS(1000));  // Yield to RTOS scheduler
}

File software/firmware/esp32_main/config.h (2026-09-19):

// ============================================================
//  Advanced SLI — ESP32 Master Configuration
//  All pin assignments, I2C addresses, timing constants,
//  and shared data structures for the entire firmware.
// ============================================================
#ifndef SLI_CONFIG_H
#define SLI_CONFIG_H

#include <Arduino.h>

// ======================== I2C BUS PINS ========================
// Bus 0: Hardware Wire — MPU6050 + AS5600 Swing Encoder
// MPU6050 confirmed working on GPIO21/22 from mpu_hx711_test.ino
#define I2C0_SDA  21
#define I2C0_SCL  22

// Bus 1: Hardware Wire1 — AS5600 Boom Lift Encoder
#define I2C1_SDA  25
#define I2C1_SCL  26

// Bus 2: Software bit-bang — AS5600 Telescope only
// MPU6050 moved to Bus 0 (confirmed working there)
#define I2C2_SDA  32
#define I2C2_SCL  33

// ======================== I2C ADDRESSES ========================
#define AS5600_ADDR   0x36
#define MPU6050_ADDR  0x68

// ======================== HX711 LOAD CELL ========================
// Pins confirmed from mpu_hx711_test.ino
#define HX711_DT_PIN         17
#define HX711_SCK_PIN        16
// Default calibration factor (counts per kg) from software/test_codes/loadcell_approx/loadcell_approx.ino
#define HX711_DEFAULT_SCALE  122000.0f
// Plausible load ceiling for a 5kg model crane (beyond this = uncalibrated or overload error)
#define MAX_VALID_LOAD_KG    10.0f

// ======================== FSR ANALOG PINS ========================
// ADC1 input-only pins — outrigger force sensors
#define FSR1_PIN  34
#define FSR2_PIN  35
#define FSR3_PIN  36
#define FSR4_PIN  39

// ======================== N20 WINCH VIA DRV8833 ========================
#define DRV_AIN1  13   // PWM / direction
#define DRV_AIN2  14   // PWM / direction
#define DRV_STBY  12   // Standby (tie to 3.3V if always-on)

// ======================== N20 QUADRATURE ENCODER ========================
#define N20_ENC_A  18  // Interrupt-capable
#define N20_ENC_B  19  // Interrupt-capable

// ======================== UART2 TO ARDUINO MEGA ========================
// Confirmed from test_codes/esp_serial_test/esp_serial_test.ino
#define MEGA_RX_PIN  23   // ESP32 GPIO23 (RX2) ← Mega Pin 18 (TX1)
#define MEGA_TX_PIN  27   // ESP32 GPIO27 (TX2) → Mega Pin 19 (RX1)
#define MEGA_BAUD    9600

// ======================== USB SERIAL TO PC ========================
#define USB_BAUD  115200

// ======================== FREERTOS TASK CONFIG ========================
// Sensor acquisition rate
#define SENSOR_RATE_HZ       100
#define SENSOR_PERIOD_MS     (1000 / SENSOR_RATE_HZ)

// Telemetry push rate to PC
#define TELEMETRY_RATE_HZ    50
#define TELEMETRY_PERIOD_MS  (1000 / TELEMETRY_RATE_HZ)

// Stack sizes (bytes) — increase if you see stack overflow crashes
#define SENSOR_TASK_STACK     4096
#define TELEMETRY_TASK_STACK  4096
#define COMMAND_TASK_STACK    4096

// Task priorities — higher number = higher priority
#define SENSOR_TASK_PRIORITY     5   // Time-critical sensor reads
#define COMMAND_TASK_PRIORITY    4   // Must respond to E-stop quickly
#define TELEMETRY_TASK_PRIORITY  3   // Can tolerate slight delays

// ======================== ENCODER CONVERSIONS ========================
// N20 encoder: ticks per full drum revolution
// 150RPM N20 with magnetic encoder typically has ~7 PPR × 4 (quadrature) × gear ratio
// Adjust after measuring your actual encoder!
#define N20_TICKS_PER_REV       840
// Rope drum diameter in mm
#define ROPE_DRUM_DIAMETER_MM   20.0f
// Derived: mm of rope per encoder tick
#define ROPE_MM_PER_TICK  ((PI * ROPE_DRUM_DIAMETER_MM) / N20_TICKS_PER_REV)

// Telescope AS5600: mm of linear travel per full encoder revolution
// Calibrated from physical test: 50mm actual = 2.625 revs (-21mm at 8mm/rev) -> 19.048 mm/rev
#define TELE_MM_PER_REVOLUTION  19.048f
#define TELE_DEFAULT_INVERT     true

// Crane physical geometry
#define BASE_BOOM_LENGTH_MM     225.0f   // 22.5 cm physical base boom


// ======================== SHARED DATA STRUCTURES ========================
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

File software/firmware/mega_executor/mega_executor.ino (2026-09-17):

// ============================================================
//  Arduino Mega — Motor Executor Firmware
//  Receives G-code commands from ESP32 via Serial1 (UART)
//  and controls 3 stepper motors via RAMPS 1.4 + A4988 drivers.
//
//  This is a "dumb" motor driver — all safety logic lives on ESP32.
//  The Mega just translates G-code into step/dir pin pulses.
//
//  RAMPS 1.4 Pin Mapping:
//    X-axis (Swing):     STEP=54, DIR=55, EN=38
//    Y-axis (Telescope):  STEP=60, DIR=61, EN=56
//    Z-axis (Boom Lift): STEP=46, DIR=48, EN=62
// ============================================================

#include <Arduino.h>
#include <ctype.h>

// ======================== RAMPS 1.4 PIN DEFINITIONS ========================
// X-axis: Swing
#define SWING_STEP  54
#define SWING_DIR   55
#define SWING_EN    38

// Y-axis: Telescope (M3)
#define TELE_STEP   60
#define TELE_DIR    61
#define TELE_EN     56

// Z-axis: Boom Lift (M2)
#define LIFT_STEP   46
#define LIFT_DIR    48
#define LIFT_EN     62

// ======================== MOTOR STATE ========================
struct StepperState {
    uint8_t stepPin;
    uint8_t dirPin;
    uint8_t enPin;
    bool    running;
    uint8_t direction;
    uint16_t speed;        // Delay between steps in microseconds
    unsigned long lastStepTime;
};

StepperState motors[3] = {
    {SWING_STEP, SWING_DIR, SWING_EN, false, 0, 1000, 0},  // M1 = Swing
    {LIFT_STEP,  LIFT_DIR,  LIFT_EN,  false, 0, 1000, 0},   // M2 = Lift
    {TELE_STEP,  TELE_DIR,  TELE_EN,  false, 0, 1000, 0}    // M3 = Telescope
};

// ======================== SERIAL BUFFER ========================
char cmdBuffer[64];
int cmdIndex = 0;

// ======================== SETUP ========================
void setup() {
    Serial.begin(115200);   // USB (for debug, optional)
    Serial1.begin(9600);    // UART from ESP32 (Pin 18=TX1, Pin 19=RX1)

    // Configure stepper pins
    for (int i = 0; i < 3; i++) {
        pinMode(motors[i].stepPin, OUTPUT);
        pinMode(motors[i].dirPin,  OUTPUT);
        pinMode(motors[i].enPin,   OUTPUT);
        digitalWrite(motors[i].enPin, LOW);  // Enable drivers (active LOW)
    }

    Serial.println("Mega Executor Ready");
    Serial1.println("$MEGA,READY");
}

// ======================== MAIN LOOP ========================
void loop() {
    // 1. Check for incoming commands from ESP32
    while (Serial1.available()) {
        char c = Serial1.read();
        if (c == '\n' || c == '\r') {
            if (cmdIndex > 0) {
                cmdBuffer[cmdIndex] = '\0';
                processCommand(cmdBuffer);
                cmdIndex = 0;
            }
        } else if (cmdIndex < (int)sizeof(cmdBuffer) - 1) {
            cmdBuffer[cmdIndex++] = c;
        }
    }

    // Also accept commands from USB Serial (for direct debugging)
    while (Serial.available()) {
        char c = Serial.read();
        if (c == '\n' || c == '\r') {
            if (cmdIndex > 0) {
                cmdBuffer[cmdIndex] = '\0';
                processCommand(cmdBuffer);
                cmdIndex = 0;
            }
        } else if (cmdIndex < (int)sizeof(cmdBuffer) - 1) {
            cmdBuffer[cmdIndex++] = c;
        }
    }

    // 2. Step any running motors using non-blocking timing
    unsigned long now = micros();
    for (int i = 0; i < 3; i++) {
        if (motors[i].running && (now - motors[i].lastStepTime >= motors[i].speed)) {
            digitalWrite(motors[i].stepPin, HIGH);
            delayMicroseconds(2);  // Minimum pulse width for A4988
            digitalWrite(motors[i].stepPin, LOW);
            motors[i].lastStepTime = now;
        }
    }
}

// ======================== COMMAND PARSER ========================
void processCommand(const char* cmd) {
    // --- T0: Emergency Stop ---
    if (cmd[0] == 'T' && cmd[1] == '0') {
        emergencyStop();
        Serial.println("E-STOP TRIGGERED");
        Serial1.println("$ACK,ESTOP");
        return;
    }

    // --- M0 Ax: Stop specific axis ---
    if (cmd[0] == 'M' && cmd[1] == '0') {
        int axis = extractParam(cmd, 'A', 0);
        if (axis >= 1 && axis <= 3) {
            motors[axis - 1].running = false;
            Serial.print("Stopped axis "); Serial.println(axis);
        }
        return;
    }

    // --- M1-M3: Motor commands ---
    if (cmd[0] == 'M' && cmd[1] >= '1' && cmd[1] <= '3') {
        int axis = cmd[1] - '0';       // 1, 2, or 3
        int speed = extractParam(cmd, 'S', 0);
        int dir   = extractParam(cmd, 'D', 0);

        int idx = axis - 1;  // Array index (0-based)

        // Convert speed (steps/sec) to step delay in microseconds
        // e.g. Speed 500 = 2000µs delay (matches RAMPS_test.ino)
        if (speed == 0) {
            motors[idx].running = false;
            return;
        }

        motors[idx].speed = 1000000UL / speed;
        motors[idx].direction = dir;
        motors[idx].running = true;

        // Set direction pin
        digitalWrite(motors[idx].dirPin, dir ? HIGH : LOW);

        Serial.print("M"); Serial.print(axis);
        Serial.print(" S"); Serial.print(speed);
        Serial.print(" D"); Serial.println(dir);
    }
}

// ======================== EMERGENCY STOP ========================
void emergencyStop() {
    for (int i = 0; i < 3; i++) {
        motors[i].running = false;
        // Optionally disable drivers for immediate coast-down:
        // digitalWrite(motors[i].enPin, HIGH);  // HIGH = disabled
    }
}

// ======================== PARAMETER EXTRACTION ========================
int extractParam(const char* line, char prefix, int defaultVal) {
    char target = toupper(prefix);
    const char* p = line;
    while (*p) {
        if (toupper(*p) == target) {
            p++;
            while (*p == ' ') p++;
            if ((*p >= '0' && *p <= '9') || *p == '-') return atoi(p);
        }
        p++;
    }
    return defaultVal;
}

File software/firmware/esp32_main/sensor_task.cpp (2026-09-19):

// ============================================================
//  Sensor Task — Implementation
// ============================================================
#include "sensor_task.h"

// Local references to driver instances (set by init)
static AS5600Driver*  _swingEnc  = nullptr;
static AS5600Driver*  _boomEnc   = nullptr;
static AS5600Driver*  _teleEnc   = nullptr;
static MPU6050Driver* _imu       = nullptr;
static HX711Driver*   _loadCell  = nullptr;
static FSRReader*     _fsr       = nullptr;
static N20Encoder*    _winchEnc  = nullptr;

// Global sensor data — declared in esp32_main.ino
extern SensorData sensorData;

void sensorTask_init(
    AS5600Driver* swingEnc,
    AS5600Driver* boomEnc,
    AS5600Driver* teleEnc,
    MPU6050Driver* imu,
    HX711Driver* loadCell,
    FSRReader* fsr,
    N20Encoder* winchEnc
) {
    _swingEnc = swingEnc;
    _boomEnc  = boomEnc;
    _teleEnc  = teleEnc;
    _imu      = imu;
    _loadCell = loadCell;
    _fsr      = fsr;
    _winchEnc = winchEnc;
}

#include <Preferences.h>

static Preferences _prefs;
static float   _boomAngleOffset = 0.0f;
static float   _tiltAngleOffset = 0.0f;
static uint8_t _boomSource      = 0;     // 0 = Roll (X) — physical MPU placement default
static uint8_t _tiltSource      = 1;     // 1 = Pitch (Y) — independent from boom
static bool    _boomInvert      = false;
static bool    _tiltInvert      = false;
static float   _teleScale       = TELE_MM_PER_REVOLUTION;
static bool    _teleInvert      = TELE_DEFAULT_INVERT;

static volatile bool    _reqImuCalibration = false;
static volatile uint8_t _reqBoomSrc = 0;
static volatile uint8_t _reqTiltSrc = 1;
static volatile bool    _reqBoomInv = false;
static volatile bool    _reqTiltInv = false;

void sensorTask_saveCalibration() {
    _prefs.begin("sli_imu", false);
    _prefs.putFloat("b_off",      _boomAngleOffset);
    _prefs.putFloat("t_off",      _tiltAngleOffset);
    _prefs.putUChar("b_src",      _boomSource);
    _prefs.putUChar("t_src",      _tiltSource);
    _prefs.putBool("b_inv",       _boomInvert);
    _prefs.putBool("t_inv",       _tiltInvert);
    _prefs.putFloat("tele_scale", _teleScale);
    _prefs.putBool("tele_inv",    _teleInvert);
    _prefs.end();
}

void sensorTask_loadCalibration() {
    _prefs.begin("sli_imu", true);
    _boomAngleOffset = _prefs.getFloat("b_off",      0.0f);
    _tiltAngleOffset = _prefs.getFloat("t_off",      0.0f);
    _boomSource      = _prefs.getUChar("b_src",      0);   // default: Roll (X)
    _tiltSource      = _prefs.getUChar("t_src",      1);   // default: Pitch (Y)
    _boomInvert      = _prefs.getBool("b_inv",       false);
    _tiltInvert      = _prefs.getBool("t_inv",       false);
    _teleScale       = _prefs.getFloat("tele_scale", TELE_MM_PER_REVOLUTION);
    _teleInvert      = _prefs.getBool("tele_inv",    TELE_DEFAULT_INVERT);
    _prefs.end();
}

void sensorTask_resetTelescope(float scale, int8_t invert) {
    bool isTuningOnly = (scale > 0.1f || invert >= 0);
    if (scale > 0.1f) {
        _teleScale = scale;
    }
    if (invert >= 0) {
        _teleInvert = (invert != 0);
    }
    if (!isTuningOnly && _teleEnc) {
        _teleEnc->setZero();
        Serial.println("$ACK,CAL2,TELE_ZEROED");
    } else {
        Serial.print("$ACK,CAL2,TELE_SAVED,SCALE:");
        Serial.print(_teleScale, 3);
        Serial.print(",INV:");
        Serial.println(_teleInvert ? "1" : "0");
    }
    sensorTask_saveCalibration();
}

void sensorTask_zeroIMU() {
    if (_imu && _imu->isConnected()) {
        float r = _imu->getRoll();
        float p = _imu->getPitch();
        // Use independently configured source axes for zeroing
        _boomAngleOffset = (_boomSource == 1) ? p : r;
        _tiltAngleOffset = (_tiltSource == 1) ? p : r;
        sensorTask_saveCalibration();
    }
}

void sensorTask_requestIMUCalibration(uint8_t boomSrc, bool boomInv, uint8_t tiltSrc, bool tiltInv) {
    _reqBoomSrc = boomSrc;
    _reqBoomInv = boomInv;
    _reqTiltSrc = tiltSrc;
    _reqTiltInv = tiltInv;
    _reqImuCalibration = true;
}

void sensorTask(void* pvParameters) {
    TickType_t lastWakeTime = xTaskGetTickCount();
    const TickType_t period = pdMS_TO_TICKS(SENSOR_PERIOD_MS);

    for (;;) {
        // Process pending IMU calibration strictly on Core 1
        // This prevents I2C bus collision with CommandTask on Core 0
        if (_reqImuCalibration) {
            _reqImuCalibration = false;
            Serial.println("$ACK,DBG,Executing IMU Cal on Core 1...");
            if (_imu && _imu->isConnected()) {
                _imu->calibrateGyro(100);
                Wire.setClock(100000);
            }
            _boomSource = _reqBoomSrc;
            _tiltSource = _reqTiltSrc;
            _boomInvert = _reqBoomInv;
            _tiltInvert = _reqTiltInv;
            sensorTask_zeroIMU();

            Serial.print("$ACK,DBG,IMU Zeroed! b_off:");
            Serial.print(_boomAngleOffset);
            Serial.print(" t_off:");
            Serial.print(_tiltAngleOffset);
            Serial.print(" b_src:");
            Serial.print(_boomSource);
            Serial.print(" t_src:");
            Serial.print(_tiltSource);
            Serial.print(" b_inv:");
            Serial.print(_boomInvert);
            Serial.print(" t_inv:");
            Serial.println(_tiltInvert);
        }

        // ---- Read all sensors ----

        // AS5600 encoders (angles in degrees)
        float swing = _swingEnc ? _swingEnc->readAngle() : 0.0f;
        float tele  = _teleEnc  ? _teleEnc->readContinuousAngle() : 0.0f;

        // MPU6050 IMU on the boom (updates internal complementary filter)
        if (_imu) _imu->update();

        float mpuRoll  = _imu ? _imu->getRoll()  : 0.0f;
        float mpuPitch = _imu ? _imu->getPitch() : 0.0f;

        // Independent axis sources for boom and tilt
        float boomBase = (_boomSource == 1) ? mpuPitch : mpuRoll;
        float tiltBase = (_tiltSource == 1) ? mpuPitch : mpuRoll;

        // Calibrated zero offset subtraction and inversion
        float rawBoom = (boomBase - _boomAngleOffset) * (_boomInvert ? -1.0f : 1.0f);
        float rawTilt = (tiltBase - _tiltAngleOffset) * (_tiltInvert ? -1.0f : 1.0f);

        float boom = (_imu && _imu->isConnected())
            ? rawBoom
            : (_boomEnc ? _boomEnc->readAngle() : 0.0f);

        // HX711 load cell (non-blocking — returns cached if not ready)
        float weight = _loadCell ? _loadCell->getWeight() : 0.0f;

        // FSR outrigger sensors (raw ADC)
        uint16_t fsrVals[4] = {0, 0, 0, 0};
        if (_fsr) _fsr->readAll(fsrVals);

        // N20 winch encoder (rope length)
        float ropeLen = _winchEnc ? _winchEnc->getRopeLengthMM() : 0.0f;

        // ---- Convert telescope angle to linear extension ----
        // Full AS5600 rotation (360°) = _teleScale mm (calibrated with direction inversion)
        float rawExtMM = (tele / 360.0f) * _teleScale;
        float extensionMM = _teleInvert ? -rawExtMM : rawExtMM;
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

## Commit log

2026-08-16 Add first prototype description for robotic arm
2026-08-22 Update project
    [Body3.stl, boom tip.stl, loadcell cap.stl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]
2026-08-24 laser cut updated
    [base plate2.dxf]
2026-09-02 Revise Week 8 entry
    Updated Week 8 entry to reflect completed prototype testing and noted issues.
2026-09-15 Add test codes for AS5600, FSR, ESP32 serial communication, Mega serial communication, and N20 motor with encoder
2026-09-16 test: add ESP32 serial communication test script
2026-09-16 feat: implement ESP32 and Mega firmware, backend configuration, and software design documentation
2026-09-16 feat: add V1 outrigger and outrigger plate STL files
    [outrigger.stl, outrigger_plate.stl]
2026-09-16 fix: Rewrite dashboard UI, fix MPU6050 & HX711 firmware bugs
    [sli_session_20260916_181005.csv, sli_session_20260916_182759.csv, sli_session_20260916_200907.csv]
2026-09-17 feat: add ESP32 firmware and React dashboard UI components
2026-09-17 feat: implement firmware drivers, backend API, and dashboard UI for SLI system
    [sli_session_20260916_181005.csv, sli_session_20260916_182759.csv, sli_session_20260916_200907.csv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]
2026-09-19 feat: add initial ESP32 firmware, backend API models, and frontend dashboard components for SLI system
    [sli_session_20260917_190712.csv, sli_session_20260917_193618.csv]
2026-09-20 docs: add project status report
    [sli_session_20260917_180221.csv, sli_session_20260917_181055.csv, sli_session_20260917_181309.csv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]
2026-09-20 added V1 hook CAD model
    [hook.stl]
2026-10-09 added new tnut joint
2026-10-23 Encoders and sensors all working
2026-10-23 Firmware v2 (RTOS restructure, software I2C), sensor calibration, dead-man motion, recording toggle
    - esp32_mainv2: task layout (core 1 sensors, core 0 comms), serial TX queue,
    storage task for flash writes, task watchdog, software I2C on all buses
    - Calibration: load cell (multi-weight), swing / telescope / rope 2-point,
    encoder zero/invert, tare and positions saved across reboots
    - N20 rope counting on PCNT, winch brake on stop
    - Dead-man motion on Mega and ESP32 winch; dashboard hold-to-move + gamepad
    - Backend: REC toggle (off by default), no ESP32 reset on connect, link-drop handling
    - esp32_main kept as the hardware-I2C version
